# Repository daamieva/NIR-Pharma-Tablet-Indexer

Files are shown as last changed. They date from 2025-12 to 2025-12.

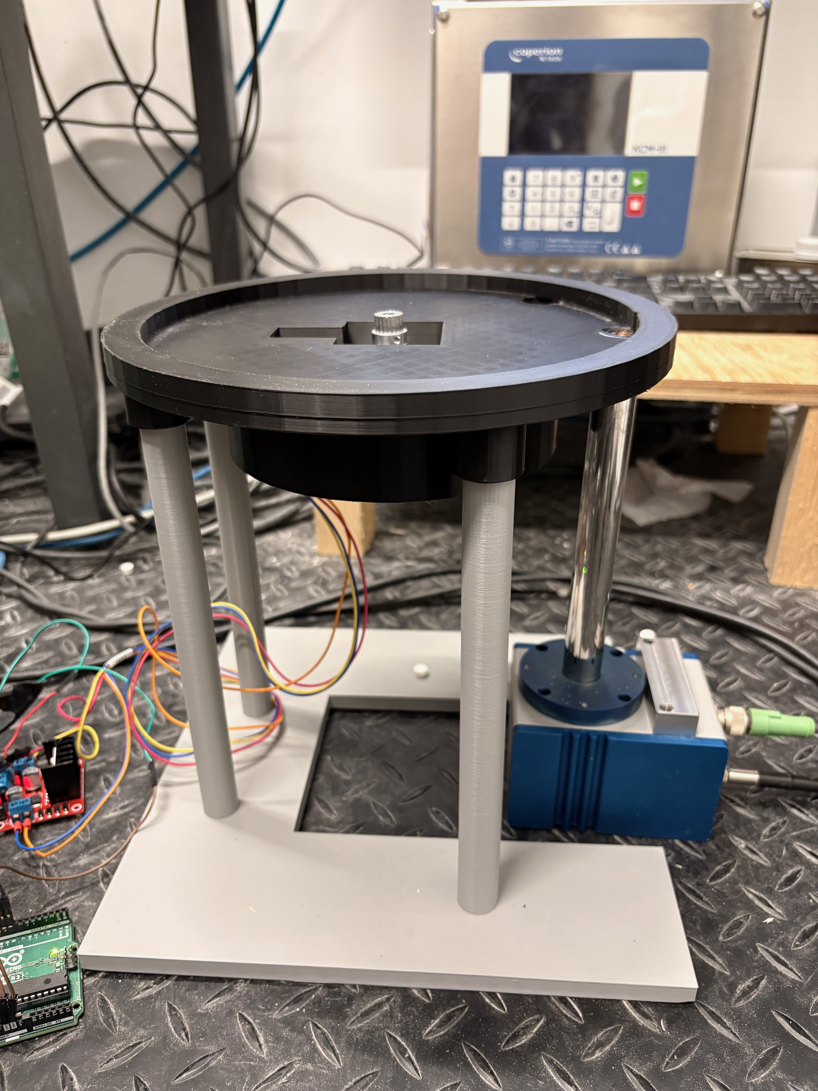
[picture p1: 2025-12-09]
media/photos/IMG_5183.jpeg

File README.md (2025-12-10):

# NIR Pharmaceutical Tablet Indexer for Continuous Manufacturing

---
## Preface
In Pharmaceuticals, there are two main types of manufacturing strategies: 
* **Batch manufacturing**: Material is made in discrete lots, with defined pauses in-between. The pauses allow for quality control, but at the cost of production time and potentially not realizing an error until an entire batch is done.
* **Continuous manufacturing**: Material flows nonstop from raw ingredients to finished product. Quality is monitored and can be altered automatically in real time using process analytical technology (PAT) tools. The main advantage here is that by improving the mechanisms of monitoring the product, product waste can be reduced.
<!-- include GROUP name -->
I am part of [`Purdue University’s Continuous Solids Processing Pilot Plant`](https://engineering.purdue.edu/CP3) at FLEX Lab, which does reasearch in the realm of continuous manufacturing for granular materials. The group has recently come up with a way to deduce the tensile strength of a tablet in a non-destructive manner by correlating it to the size distribution of granules using a near-infrared (NIR) sensor. The NIR sensor measures the NIR spectra of each tablet to essentially see how dense each tablet is. This density is critical for tablet manufacturing. if the tablet is not dense enough, it is succeptible to breaking in transport. If it is too dense, it can have problems with taking too long to dissolve once ingested. If the tablet density is determined to be undesireable by the NIR sensor, feedback can be sent upstream to the tablet press, which can then change the pressure at which it presses tablets. This can be another way to reduce material in a continuous manufacturing line, if we can implement the technology properly. This is where my prototype comes in to the picture.

I was brought onto the team to explore the possibility of making this nondestructive testing method also “in-line”, meaning it can occur in the continuous manufacturing line automatically without slowing down the flow of production.

## Overview
The system I created moves the tablets onto and off of the NIR sensor using a starwheel device. I was inspired to make this design "revolve" (no pun intended) around the starwheel technology after seeing it used to move bottled pharmaceuticals and other objects within assembly lines. The starwheel is powered by a stepper motor and arduino. 
This is the first prototype, so the goal here was to just prove that a tablet could be indexed onto and off of the sensor in a quick and controlled manner, all while displaying a consistent measurement of the light distribution for each tablet. Check out how it works in [`media/`](/media/)

*The following document regarding IP [`Purdue Research IP`](https://www.purdue.edu/research/oevprp/regulatory-affairs/intellectual-property-faq.php) shows that since I was an unpaid undergraduate researcher and did not use Purdue funds or grants to complete my work, this project is my intellectual property.*

---

### Hardware Components
* Stepper Motor: NEMA17
* Motor driver: L298N
* Microcontroller: Arduino UNO (any similar microcontroller can be used)
* Frame: 3D-printed parts
* Sensor: NIR Sensor
* Power: 12V supply

---

### CAD Files & Engineering Drawings
All custom-designed components are in [`hardware/mechanical/cad/`](hardware/mechanical/cad/).

Include:
* NIR Tablet Indexer Stand   
* NIR Tablet Indexer Stator
* NIR Tablet Indexer Rotor
* NIR sensor dummy representation for testing

Engineering drawings are in [`hardware/mechanica/drawings/](hardware/mechanical/drawings/)

---

### Wiring Diagram
Schematic for electronical components is in [`hardware/electronics/`](hardware/electronics/)

---

### Software: Arduino Stepper Indexer
A simple, configurable 45° indexing mechanism controlled by an Arduino + L298N driver.

Code and documentation here: [`software/`](software/)

---

## Future Improvements
The NIR sensor used needed to be shipped back to the company which lent it. Therefore, we were unable to capture as much data as desired. However, when the project resumes, I have the following improvements in mind:
* Alter base leg height to match sensor height.
* Add ramp to use gravity to feed tablets from hopper to the starwheel one at a time. This will eliminate the need for me to place tablets onto the base, and allow integration into continuous manufacturing line.
* Add pathway for tablets to go after being measured. Currently there is just a hole in the base where they drop out from, but the next iteration will include a ramp to guide them through the process. 
* Create closed loop in some manner to be able to feed signal upstream and alter tablet composition parameters as needed.

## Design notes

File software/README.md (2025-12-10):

# **Starwheel Indexing Stepper Controller**

This Arduino sketch drives a stepper motor used in a **starwheel / indexing mechanism**.
The system rotates the wheel a fixed number of degrees, pauses, and repeats — ideal for simple indexing mechanism.

---

## **Features**

* Fixed-angle indexing (default: **45° per cycle**)
* Adjustable motor RPM
* Adjustable pause time between movements
* Simple serial interface: **pause** and **resume** commands
* Built-in optional coil-release logic to reduce motor/driver heat
* Uses the Arduino **Stepper** library (included by default — no extra libraries required)

---

## **Hardware Setup**

| Component | Notes |
| --- | --- |
| Stepper Motor | 200 steps/rev (1.8°/step typical NEMA 17 or similar) |
| Driver | L298N or similar H-bridge driver |
| Arduino Pins  | 8, 9, 10, 11 → connected to motor driver inputs |

Modify these if your wiring differs:

```cpp
const int motorPins[4] = {8, 9, 10, 11};
```

---

## **Configurable Parameters**

You can tune the motor motion by editing these values:

```cpp
const float moveDegrees = 45.0;   // degrees per indexing cycle
const int pauseTime = 5*1000;     // milliseconds between movements
const int motorSpeed = 10;        // RPM
```

**Typical use-cases:**

* Increase `motorSpeed` → faster rotation
* Increase `pauseTime` → longer dwell time
* Adjust `moveDegrees` → change indexing angle

---

## **Serial Control**

To control the motor, open the Serial Monitor.

Send:

| Command | Function |
| --- | --- |
| `p` | Pause the motor  |
| `r` | Resume operation |

Messages will print confirming each action.

---

## **How to Upload**

1. Open the `.ino` file in **Arduino IDE** or VS Code with the Arduino extension.
2. Select the correct **board** and **port**.
3. Click **Upload**.

No external libraries needed — `Stepper.h` comes bundled with Arduino IDE (Just assure you include it at the beginning of the sketch).

---

## **Folder Structure**

```
software/
  code/
    StepMotorCode.ino
```

---

## **Notes**

* Coils auto-release after each movement to reduce heat.
  If you need holding torque, comment out the coil-release section.
* If direction is reversed, switch:

```cpp
motor.step(+stepsToMove);
```

to

```cpp
motor.step(-stepsToMove);
```

---

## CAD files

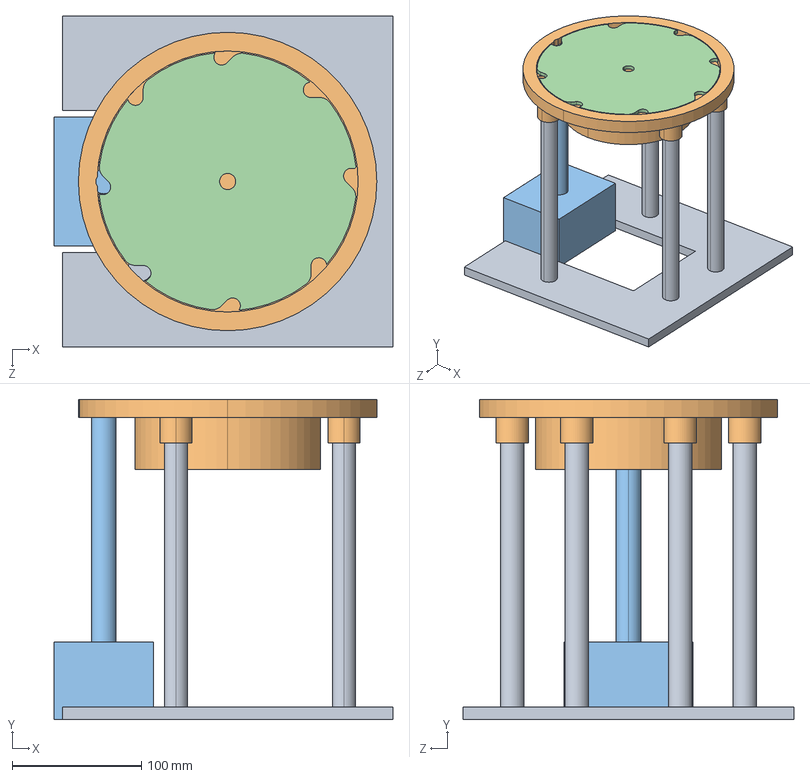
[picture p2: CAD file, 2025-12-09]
hardware/mechanical/cad/assembly.STEP
262.4 x 248.0 x 256.0 mm
MP5Baseblate
MVP4_base
NIR_Probe
MVP4_top

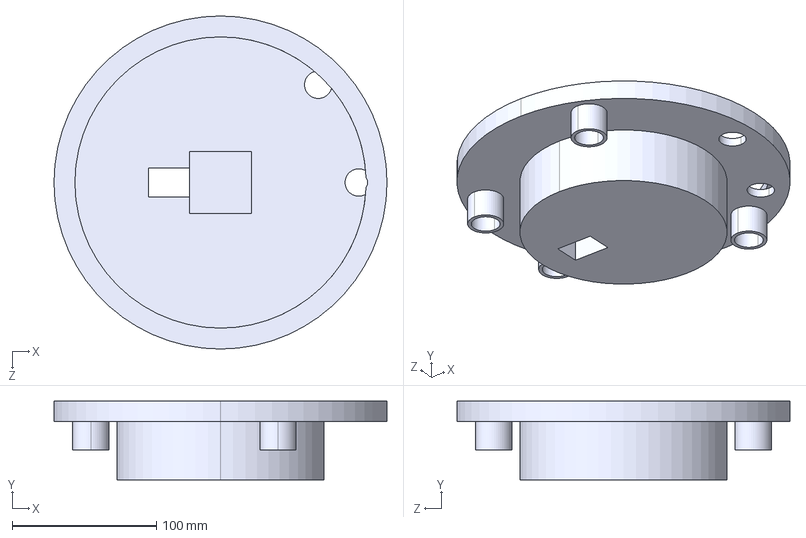
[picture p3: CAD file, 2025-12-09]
hardware/mechanical/cad/starwheel stator.STEP
231.0 x 54.5 x 231.0 mm

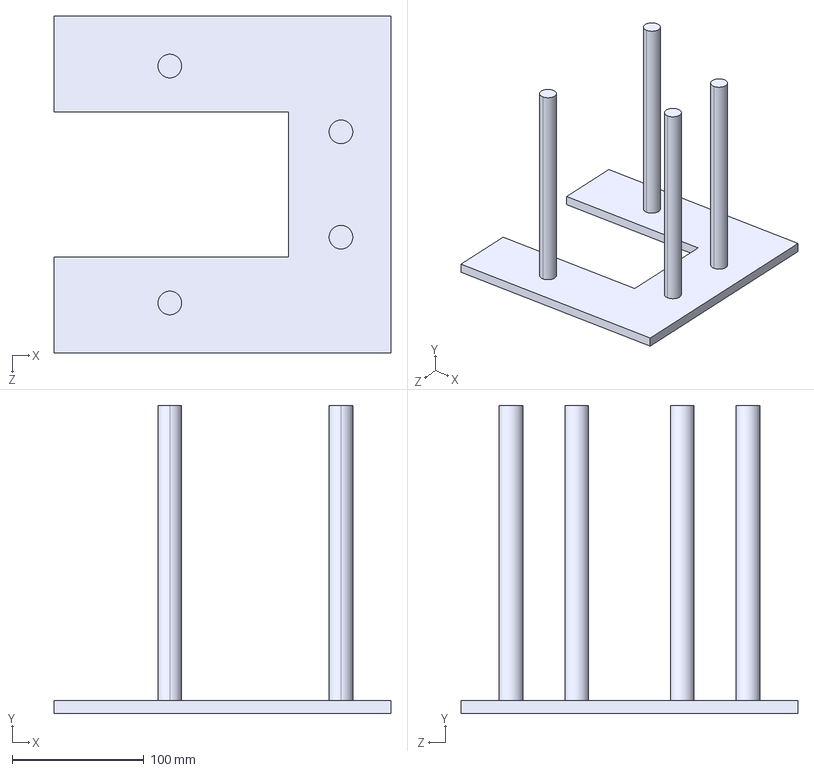
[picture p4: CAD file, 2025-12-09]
hardware/mechanical/cad/starwheel base.STEP
256.0 x 234.0 x 256.0 mm

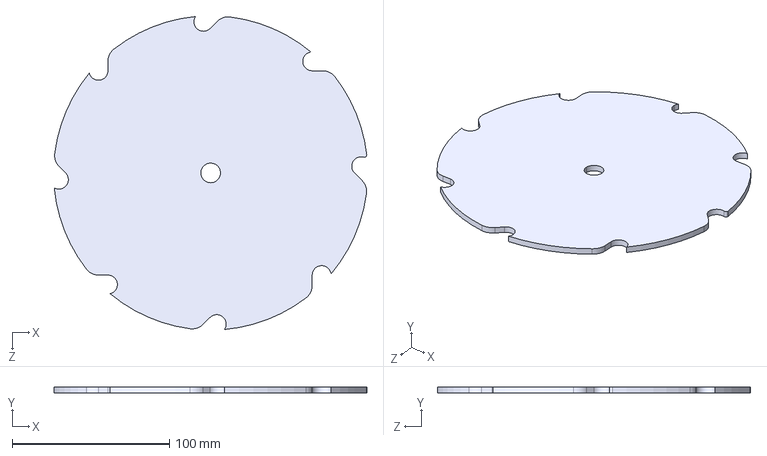
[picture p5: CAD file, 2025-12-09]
hardware/mechanical/cad/starwheel rotor.STEP
198.9 x 4.00 x 199.2 mm

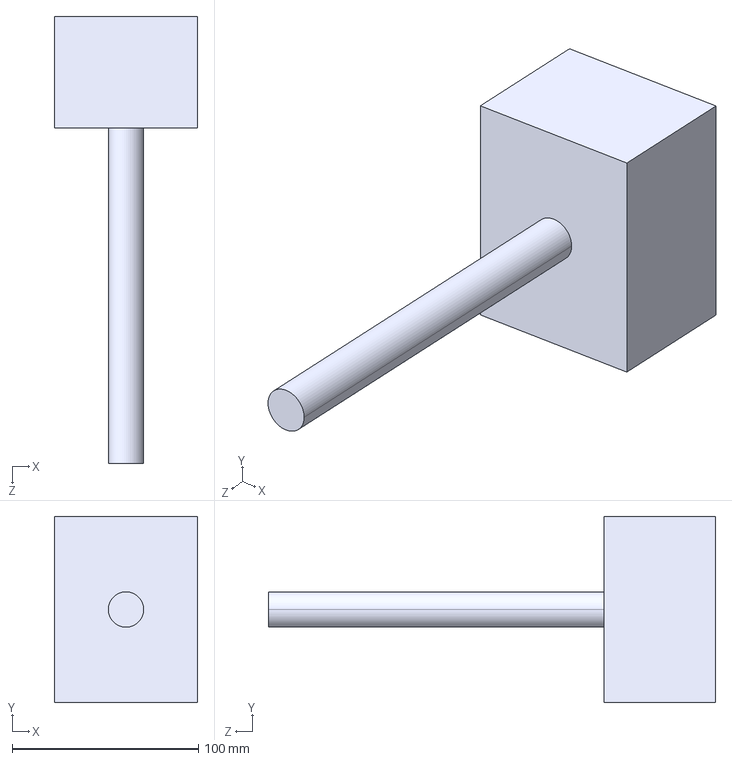
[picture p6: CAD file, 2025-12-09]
hardware/mechanical/cad/NIR probe dummy.STEP
77.0 x 100.0 x 240.0 mm

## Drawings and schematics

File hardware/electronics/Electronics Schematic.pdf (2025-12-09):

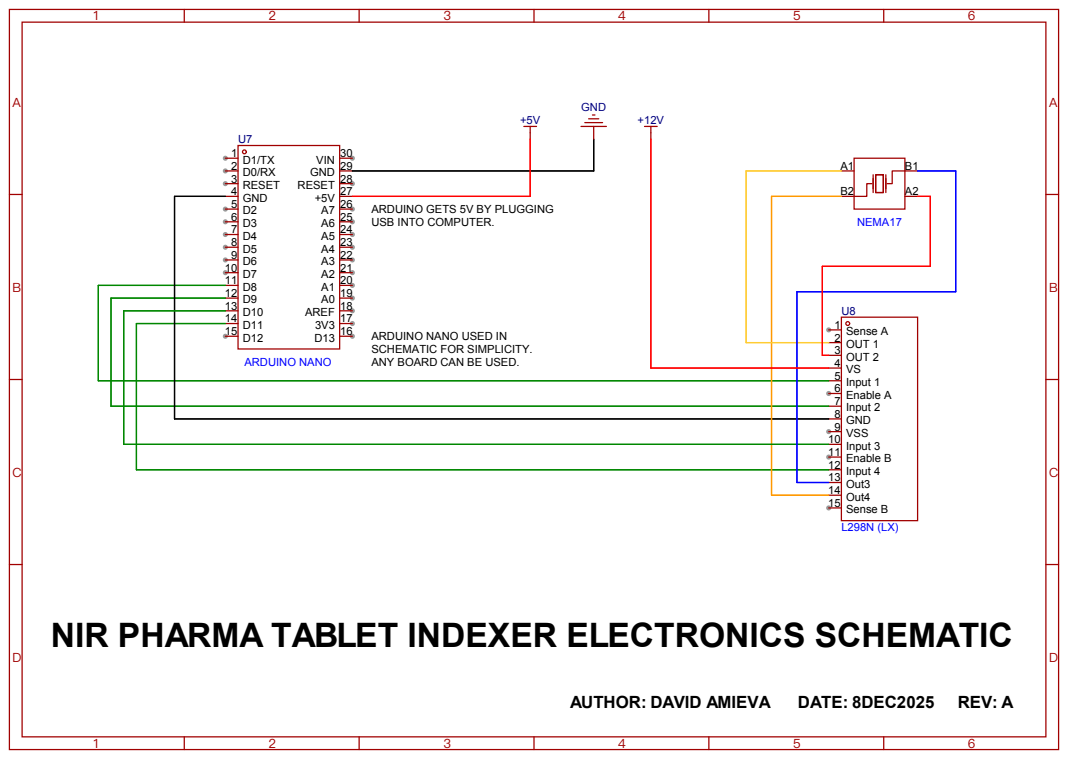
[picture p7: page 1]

ARDUINO GETS 5V BY PLUGGING
USB INTO COMPUTER.

NEMA17
Sense B 15 Out4 14 Out3 13 Input 4 12 Enable B 11 Input 3 10 VSS 9 GND 8 Input 2 7 Enable A 6 Input 1 5 VS 4 OUT 2 3 OUT 1 2 Sense A 1

ARDUINO NANO USED IN
SCHEMATIC FOR SIMPLICITY.
ANY BOARD CAN BE USED.

NIR PHARMA TABLET INDEXER ELECTRONICS SCHEMATIC

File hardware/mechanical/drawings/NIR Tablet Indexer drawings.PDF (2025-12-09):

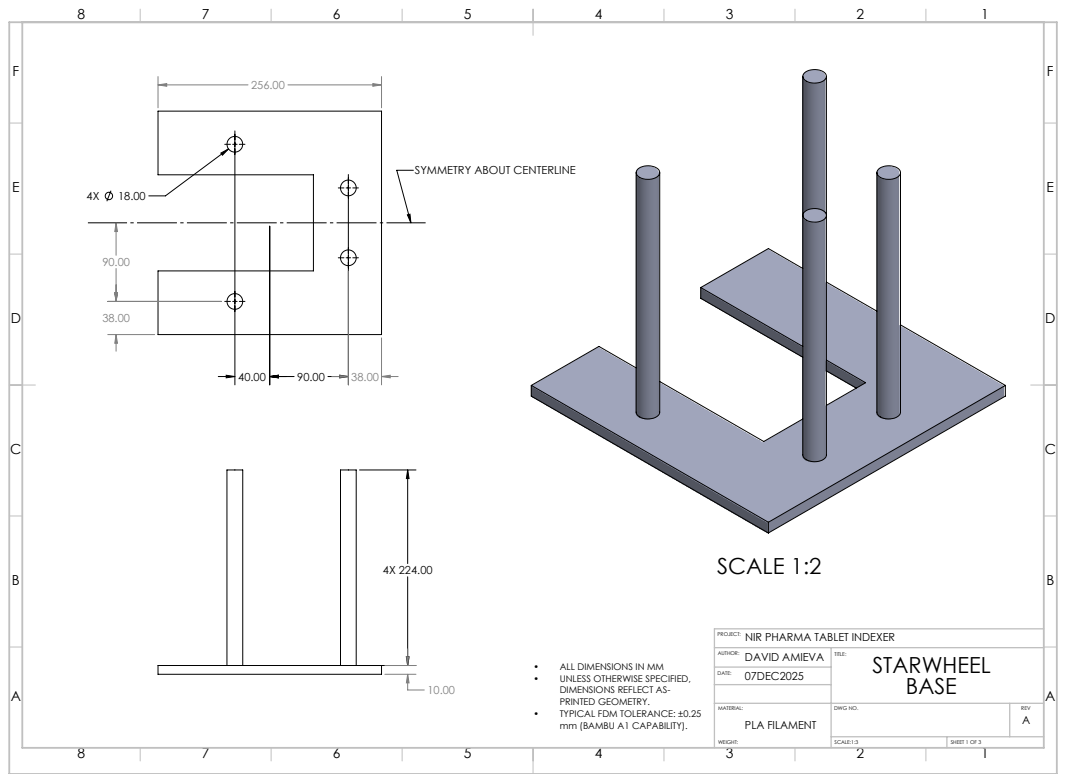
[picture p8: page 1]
SCALE 1:2

SYMMETRY ABOUT CENTERLINE

NIR PHARMA TABLET INDEXER
DAVID AMIEVA
07DEC2025

• ALL DIMENSIONS IN MM
• UNLESS OTHERWISE SPECIFIED,
DIMENSIONS REFLECT AS-
PRINTED GEOMETRY.
• TYPICAL FDM TOLERANCE: ±0.25
mm (BAMBU A1 CAPABILITY).

MATERIAL: PLA FILAMENT WEIGHT: | DWG NO. | REV A

SCALE:1:3 | SHEET 1 OF 3

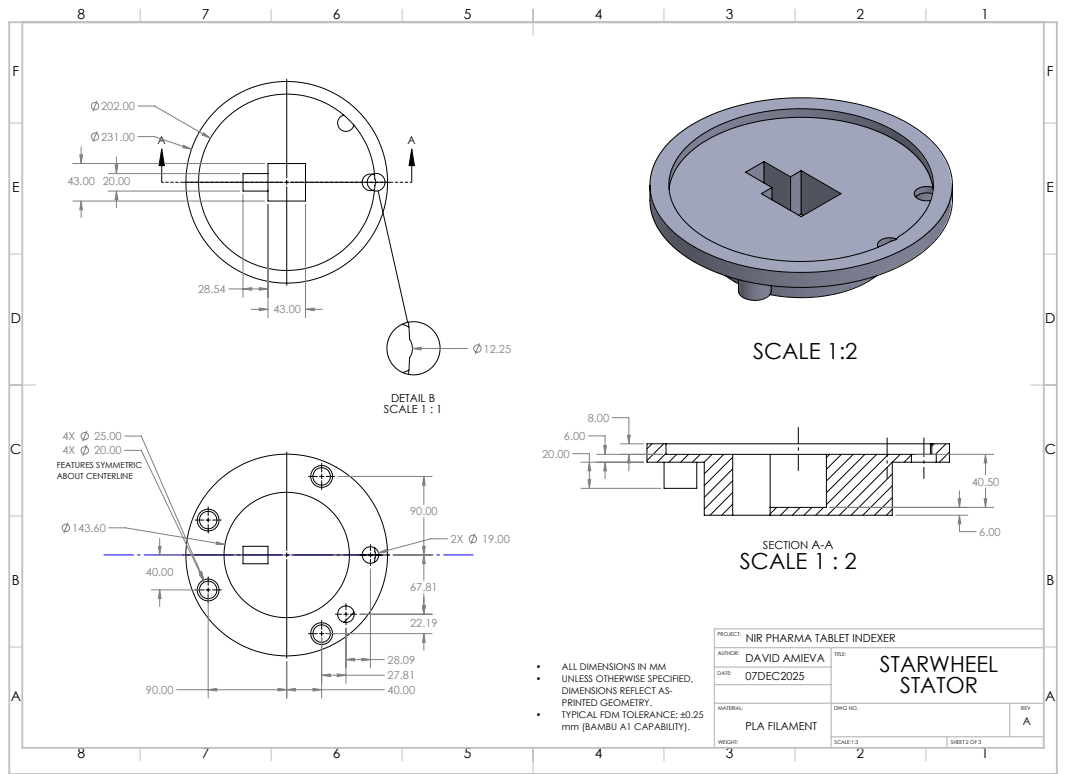
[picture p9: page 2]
SCALE 1:2; SECTION A-A SCALE 1 : 2; DETAIL B SCALE 1 : 1; FEATURES SYMMETRIC ABOUT CENTERLINE

NIR PHARMA TABLET INDEXER
DAVID AMIEVA
07DEC2025

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

WEIGHT: | | A PLA FILAMENT

SCALE:1:3 | SHEET 2 OF 3

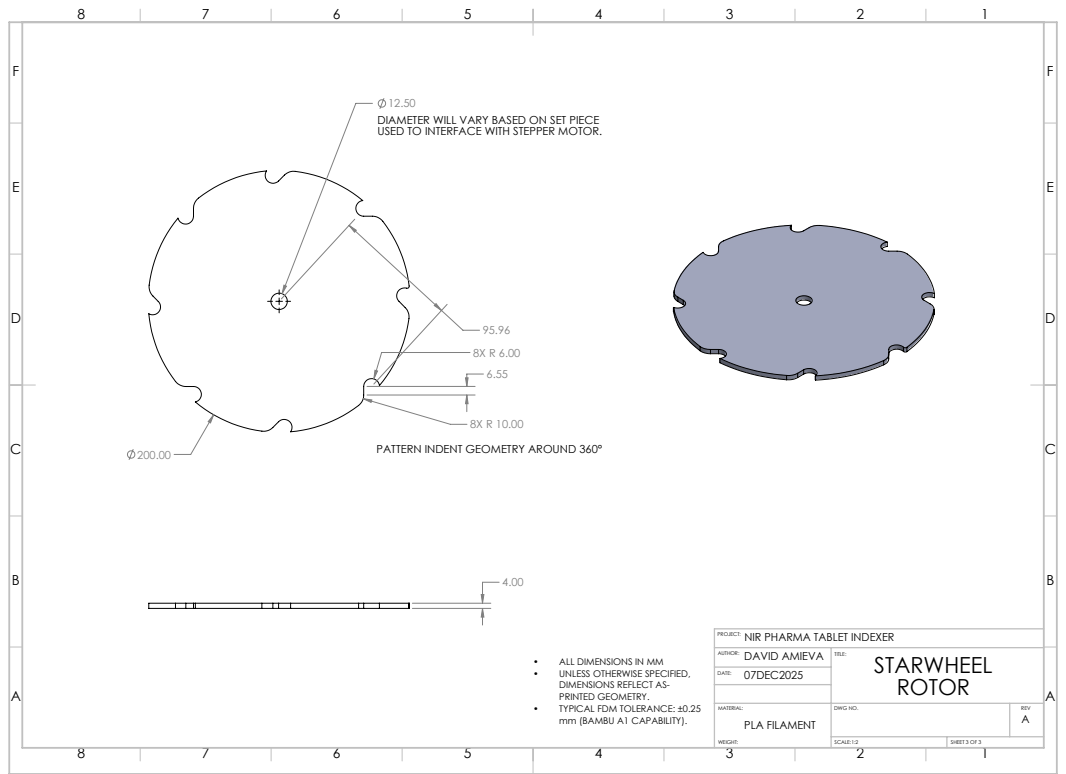
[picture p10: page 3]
SCALE 1:2

DIAMETER WILL VARY BASED ON SET PIECE
USED TO INTERFACE WITH STEPPER MOTOR.

PATTERN INDENT GEOMETRY AROUND 360°

NIR PHARMA TABLET INDEXER

DAVID AMIEVA AUTHOR: | TITLE: STARWHEEL ROTOR REV

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

WEIGHT: | | A PLA FILAMENT

SCALE:1:2 | SHEET 3 OF 3

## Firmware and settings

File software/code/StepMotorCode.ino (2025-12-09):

#include <Stepper.h> // Stepper library for stepper motors

// --- Motor Setup ---
const int stepsPerRevolution = 200;      // 1.8° per step → 200 steps = 360°
const int motorPins[4] = {8, 9, 10, 11}; // Pins connected to L298N inputs IN1–IN4

// Create Stepper motor object
Stepper motor(stepsPerRevolution, motorPins[0], motorPins[1], motorPins[2], motorPins[3]);

// --- User Settings ---
const float moveDegrees = 45.0;          // Rotation per cycle
const int pauseTime = 5 * 1000;          // Pause between moves (ms)
const int motorSpeed = 10;               // RPM

// Pause flag
bool paused = false;

void setup() {
  motor.setSpeed(motorSpeed);

  // Configure coil control pins (required for manual de-energizing)
  pinMode(8, OUTPUT);
  pinMode(9, OUTPUT);
  pinMode(10, OUTPUT);
  pinMode(11, OUTPUT);

  Serial.begin(9600);
  Serial.println("Stepper 45-degree indexing started...");
  Serial.println("Press 'p' to PAUSE, 'r' to RESUME.");
  Serial.println("Motor holding torque ENABLED by default.");
  Serial.println("To ENABLE coil de-energizing, uncomment the block at the bottom of loop().");
}

void loop() {

  // --- SERIAL PAUSE / RESUME ---
  if (Serial.available()) {
    char cmd = Serial.read();

    if (cmd == 'p') {
      paused = true;
      Serial.println("Motor PAUSED.");

      // OPTIONAL: De-energize while paused
      // Uncomment next 4 lines to disable torque when paused
      /*
      digitalWrite(8, LOW);
      digitalWrite(9, LOW);
      digitalWrite(10, LOW);
      digitalWrite(11, LOW);
      */
    }

    if (cmd == 'r') {
      paused = false;
      Serial.println("Motor RESUMED.");
    }
  }

  // If paused → stop movement loop
  if (paused) {
    delay(100);
    return;
  }

  // --- MOTOR MOVEMENT ---
  int stepsToMove = (moveDegrees / 360.0) * stepsPerRevolution;

  Serial.print("Moving ");
  Serial.print(moveDegrees);
  Serial.println(" degrees...");

  motor.step(+stepsToMove);   // Change to -stepsToMove for CCW

  // --- PAUSE BETWEEN MOVEMENTS ---
  Serial.print("Pausing for ");
  Serial.print(pauseTime);
  Serial.println(" ms...");
  delay(pauseTime);

  // -------------------------------------------------------------------
  // OPTIONAL: DE-ENERGIZE MOTOR COILS AFTER EACH MOVE TO SAVE POWER AND REDUCE HEAT
  //
  // ENABLE THIS BLOCK *ONLY IF YOU WANT*:
  //  - Lower heat
  //  - Lower power usage
  //  - No holding torque between steps
  //  - Shaft can spin freely if pushed
  //
  // !!! DEFAULT: DISABLED (motor stays energized to hold position)
  //
  // To enable, remove the /* */ around this block:
  /*
  digitalWrite(8, LOW);
  digitalWrite(9, LOW);
  digitalWrite(10, LOW);
  digitalWrite(11, LOW);
  Serial.println("Coils de-energized.");
  */
  // -------------------------------------------------------------------
}
